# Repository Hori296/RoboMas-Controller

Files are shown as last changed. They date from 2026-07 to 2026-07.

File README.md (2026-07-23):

# RoboMaster Controller

STM32を用いて設計・開発した、RoboMaster M2006 / M3508用モータコントローラです。

本リポジトリでは、回路設計・基板設計・ファームウェアを公開しています。
ロボット開発や組込みシステムで再利用できることを目的として製作しました。

---

## 概要

本コントローラは、DJI RoboMasterシリーズのM2006・M3508モータをCAN通信で制御するためのモータコントローラです。

速度制御・位置制御の両方に対応しており、連続角度推定やソフトウェアによる原点リセットなど、ロボット開発で扱いやすい機能を実装しています。

---

## 主な機能

- M2006 / M3508 モータ対応
- CAN通信による制御
- 速度制御（PID）
- 位置制御（カスケードPID）
- エンコーダ多回転角度推定
- ソフトウェア原点リセット
- 通信タイムアウト保護（500 ms）
- デバッグ情報送信（速度・位置誤差）
- RGB LEDによる状態表示

---

## 設計方針・意図

本コントローラは、M2006・M3508を今後のロボット開発で繰り返し利用できることを目的として設計しています。  
機能追加を前提とするのではなく、速度制御・位置制御・多回転角度推定・通信タイムアウト保護など、実際のロボット運用に必要な機能を一つの基板にまとめています。  
私自身がM2006・M3508モータを複数所有しており、今後のロボット開発でも継続して使用する予定です。そのため、毎回制御プログラムを作り直すことなく、共通で利用できるモータコントローラとして設計しました。

---

## ハードウェア

### マイコン

- STM32F446RE

### 通信

- CAN1
    - 上位PC・マイコンとの通信
- CAN2
    - RoboMaster ESCとの通信

### 制御周期

- 制御周期：1 ms（タイマ割り込み）
- CAN受信：受信割り込み

---

## 通信仕様

### 制御コマンド
|ID|num|
|---|---|
|0x221|motor1|
|0x222|motor2|
|0x223|motor3|
|0x224|motor4|

|Byte|内容|
|---|---|
|0|モータ種類|
|1|制御モード|
|2-3|目標値(int16 /1000)|
|4|Enable|
|5|角度リセット|
|6-7|予約|

### モータ種類

|値|内容|
|---|---|
|1|M2006|
|2|M3508|

### 制御モード

|値|内容|
|---|---|
|1|速度制御|
|2|位置制御|

### デバッグ情報

|ID|0~1|2~3|4~5|6~7|
|---|---|---|---|---|
|0x220|motor1_diff|motor2_diff|motor3_diff|motor4_diff|

---

## 安全機能

500 ms以上制御コマンドを受信しなかった場合、

- モータ停止
- PIDリセット
- 出力0

を実行し、通信断による暴走を防止します。

---

## 写真

|基板|3D|
|---|---|
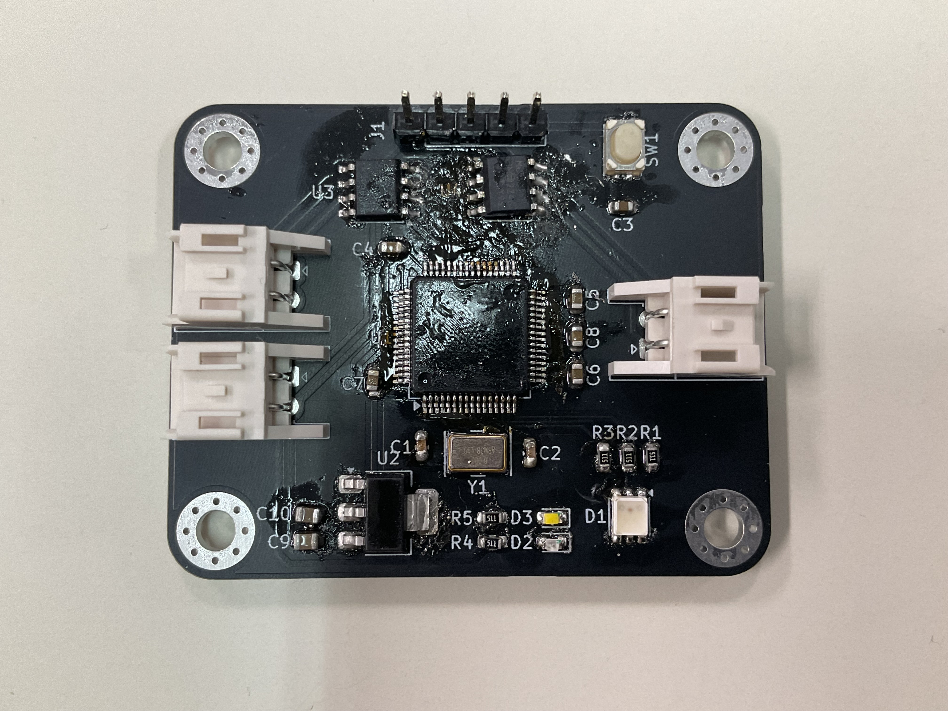
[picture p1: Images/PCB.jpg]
PCB
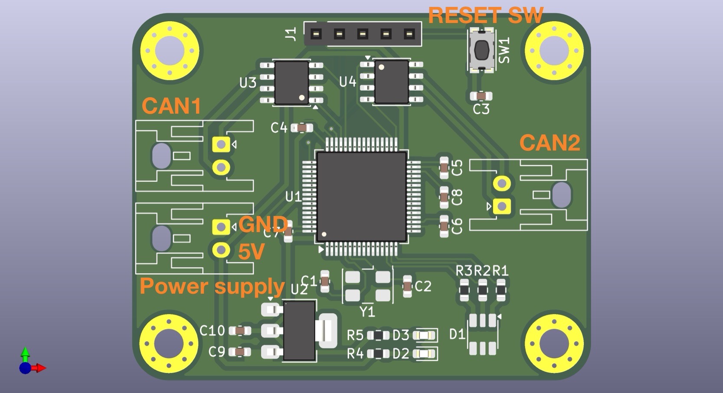
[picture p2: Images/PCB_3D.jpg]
3D
|||

---

## 動作

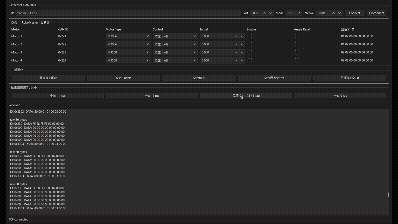
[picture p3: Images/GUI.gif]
demo_GUI

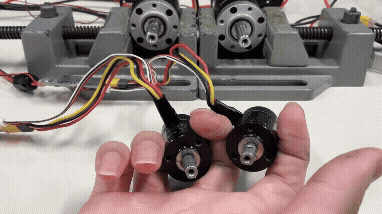
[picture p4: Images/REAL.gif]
demo_3D

demo_LED

※gif画像のためにいろいろしたら，LEDの色おかしくなった( ˊᵕˋ ;)

---

## フォルダ構成

```
Firmware/
    inc
    src
    README

PCB/
    pcb
    sch
    step
    production (JLCPCB発注用)
    README
```

---

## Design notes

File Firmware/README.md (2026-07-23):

# Firmware

## 環境
- system work bench for STM32
- HAL Driver : v1.7.5 (CAN Legacy)
- STMStudio
- 舞鶴高専ロボコン部内ライブラリ使用（Sken_library）

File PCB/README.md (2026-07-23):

# 回路設計

## 環境
- KiCad 9.0

## 使用部品
- STM32F446RET6
- MCP2551-I-SN $\times 2$
- AZ118Ch-3.3TRG1
- SMLVN6RGB
- XA-Connector 2pin $\times 3$

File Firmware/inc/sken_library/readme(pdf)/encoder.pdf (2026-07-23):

# encoder

## インクリメンタル式ロータリーエンコーダのパルスをカウントするクラス．

# struct Encoder_data

## エンコーダからの取得値を格納する関数。タイマー割り込みと合わせるて使う。

[要素]

## カウンタ値 回転数[回転]

角度[°]

## 移動距離[mm]

## 速度[mm/s] 回転速度[rps]

## [要素一覧]

# class Encoder

# void Encoder::init(Pin a_pin,Pin b_pin,TimerNumber tim_num)

## エンコーダのピンとタイマー番号を設定する． 使用することができるタイマーは1,2,3,4,5,8のチャンネル1とチャンネル2である． エンコーダのカウントに使用するタイマーはチャンネル3とチャンネル4も含めてPWM出力に使用する ことはできない．

## [パラメータ] チャンネル1のピン番号 チャンネル2のピン番号 タイマー番号

## [戻り値]

なし

## [サンプルコード] タイマー2をエンコーダモードに設定する

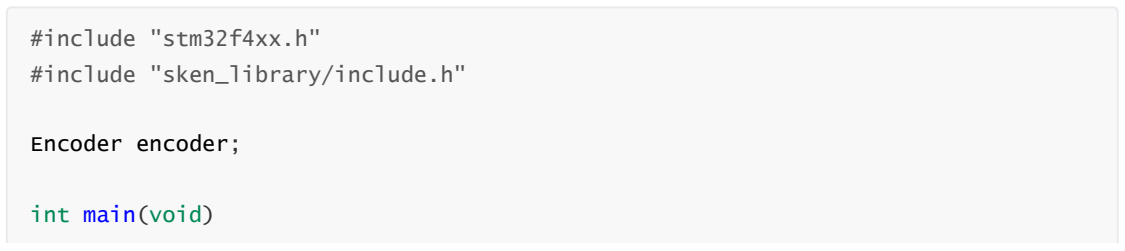
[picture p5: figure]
#include "stm32f4xx.h"; #include "sken_library/include.h"; Encoder encoder;; int main(void)

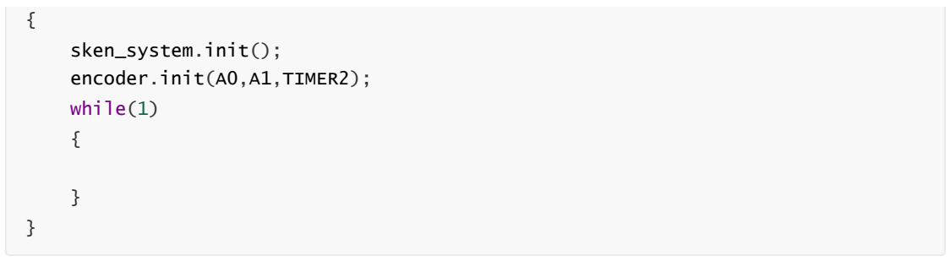
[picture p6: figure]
sken_system.init();; encoder.init(A0,A1,TIMER2);; while(1)

# int Encoder::read(void)

## カウンタの値を取得することができる． カウンタの値は-30000から30000までである．

## [パラメータ]

なし

## [戻り値] カウンタ値

## [サンプルコード]

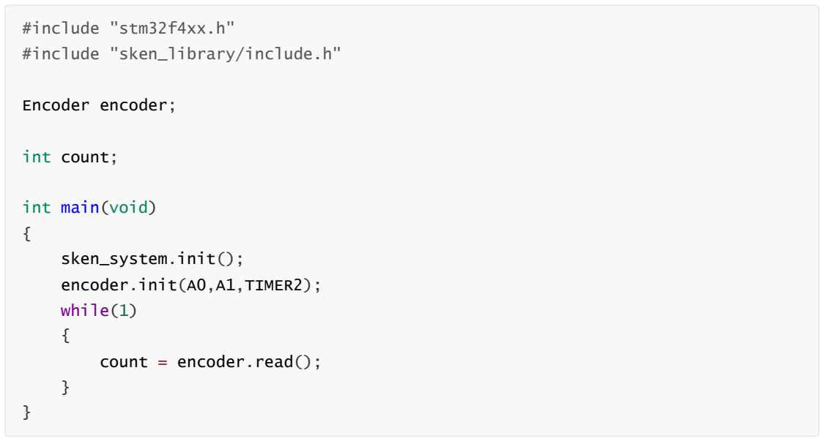
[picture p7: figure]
#include "stm32f4xx.h"; #include "sken_library/include.h"; Encoder encoder;; int count;; int main(void); sken_system.init();; encoder.init(A0,A1,TIMER2);; while(1); count = encoder.read();

# void Encoder::interrupt(Encoder_data* encoder_data)

## Encoder_data構造体にエンコーダからの取得値を格納する関数。タイマー割り込み関数内で使用す

る。

## [パラメータ]

## Encoder_data構造体アドレス

## [戻り値]

なし

## [サンプルコード] タイマー割り込みで取得値を格納する

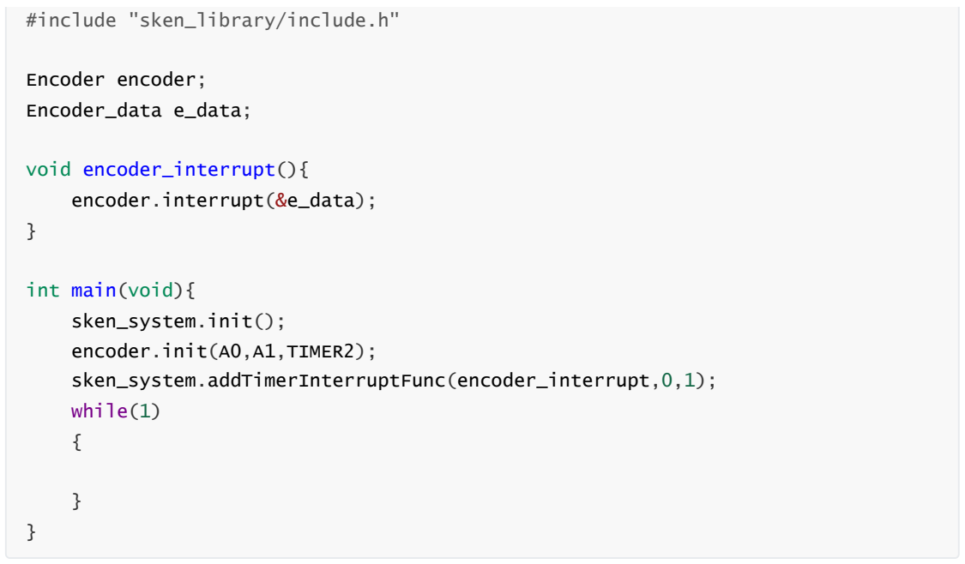
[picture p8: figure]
#include "sken_library/include.h"; Encoder encoder;; Encoder_data e_data;; void encoder_interrupt(){; encoder.interrupt(&e_data);; int main(void){; sken_system.init();; encoder.init(A0,A1,TIMER2);; sken_system.addTimerInterruptFunc(encoder_interrupt,0,1);; while(1)

# void Encoder::reset(void)

## カウンタの値をリセットする

## [パラメータ]

なし

## [戻り値]

なし

## [サンプルコード] カウンタの値が10000を超えた時にリセットする

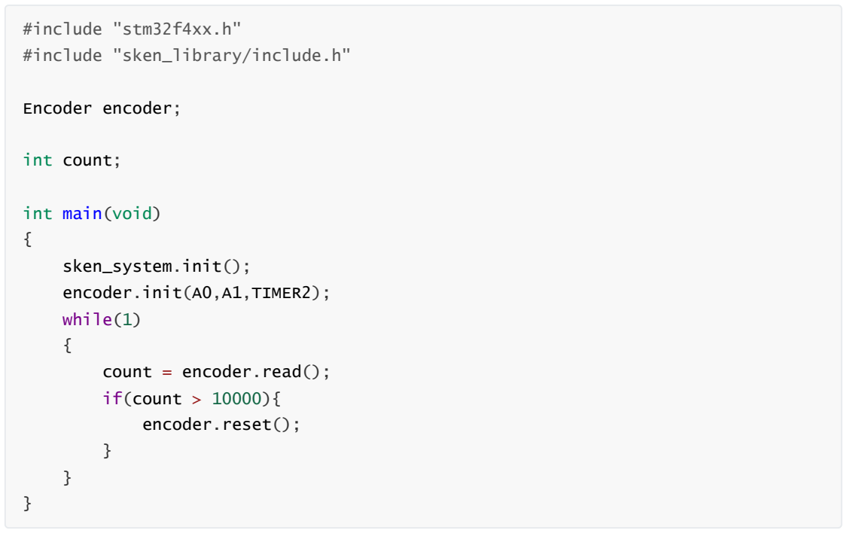
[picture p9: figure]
#include "stm32f4xx.h"; #include "sken_library/include.h"; Encoder encoder;; int count;; int main(void); sken_system.init();; encoder.init(A0,A1,TIMER2);; while(1); count = encoder.read();; if(count > 10000){; encoder.reset();

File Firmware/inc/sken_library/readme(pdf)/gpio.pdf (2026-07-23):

# gpio

## GPIOピンの⼊出⼒をあつかう

# enum Mode

## ⼊出⼒の設定

# enum PinState

## ⼊出⼒状態

# class Gpio

# void Gpio::init(Pin pin,Mode pin_mode)

## ピンの⼊出⼒設定 デジタル出⼒とデジタル⼊⼒の設定で使⽤する． [パラメータ] ピン番号 ⼊出⼒の設定

## [戻り値]

なし

## [サンプルコード] A5ピンをデジタル出⼒に設定する

LOW
HIGH

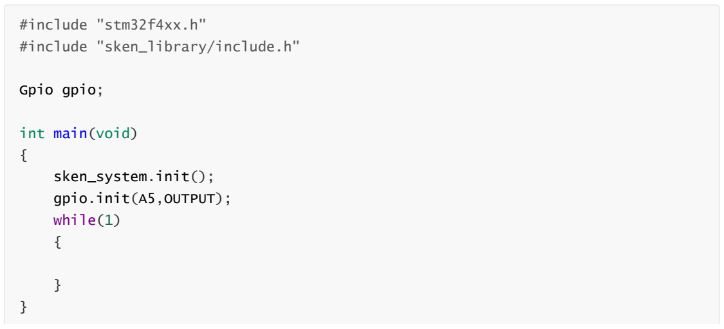
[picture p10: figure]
#include "stm32f4xx.h"; #include "sken_library/include.h"; Gpio gpio;; int main(void); sken_system.init();; gpio.init(A5,OUTPUT);; while(1)

# void Gpio::init(Pin pin,Mode pin_mode,TimerNumber tim_num,TimerChannel tim_ch,int frequency = 16800)

## ピンの⼊出⼒設定 PWM出⼒の設定で使⽤する．

## [パラメータ] ピン番号 ⼊出⼒の設定 タイマー番号 タイマーチャンネル

## PWM周波数

## [戻り値]

なし

## [サンプルコード] A5ピンをPWM出⼒に設定する

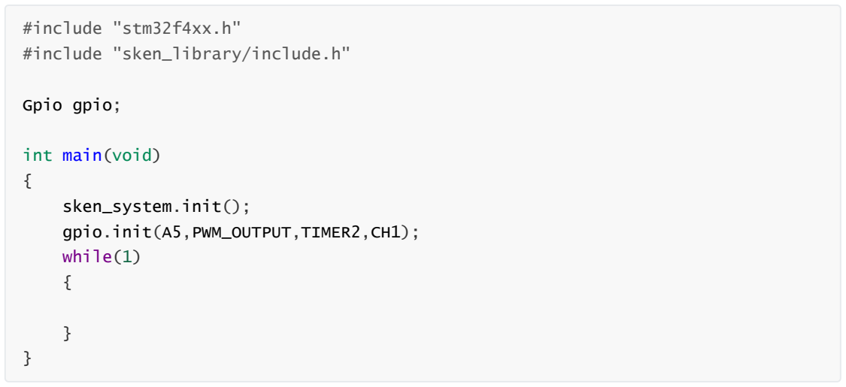
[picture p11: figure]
#include "stm32f4xx.h"; #include "sken_library/include.h"; Gpio gpio;; int main(void); sken_system.init();; gpio.init(A5,PWM_OUTPUT,TIMER2,CH1);; while(1)

# void Gpio::write(PinState state)

## 出⼒に設定している場合，ピンからHIGHまたはLOWを出⼒することができる

## [パラメータ] 出⼒状態 [戻り値]

なし

## [サンプルコード] A5ピンをデジタル出⼒に設定し，HIGHを出⼒する

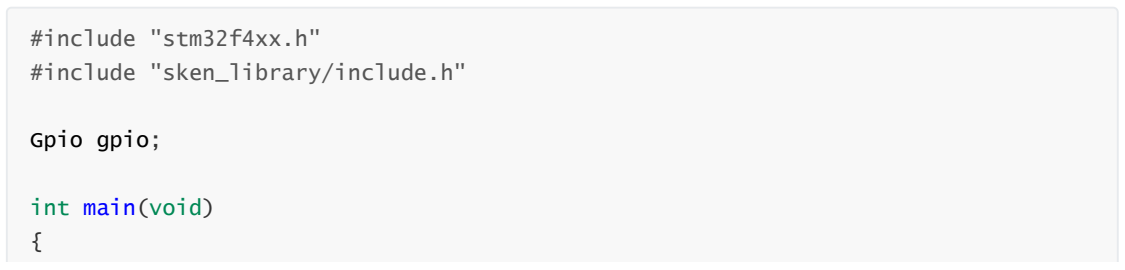
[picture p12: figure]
#include "stm32f4xx.h"; #include "sken_library/include.h"; Gpio gpio;; int main(void)

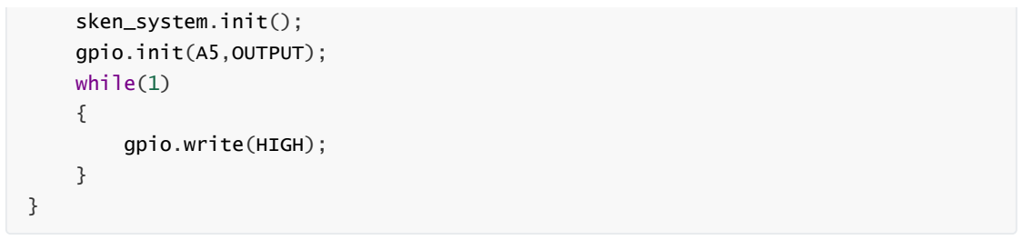
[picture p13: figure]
sken_system.init();; gpio.init(A5,OUTPUT);; while(1); gpio.write(HIGH);

# void Gpio::write(double percentage)

## PWM出⼒に設定されている場合矩形波が出⼒される． ただし，同じタイマーにエンコーダやRCサーボ信号を使⽤している場合はたとえチャンネルが違った としても正しい出⼒が⾏われない． [パラメータ]

出⼒[%]

## [戻り値]

なし

## [サンプルコード] A5ピンから50%のPWMを出⼒する

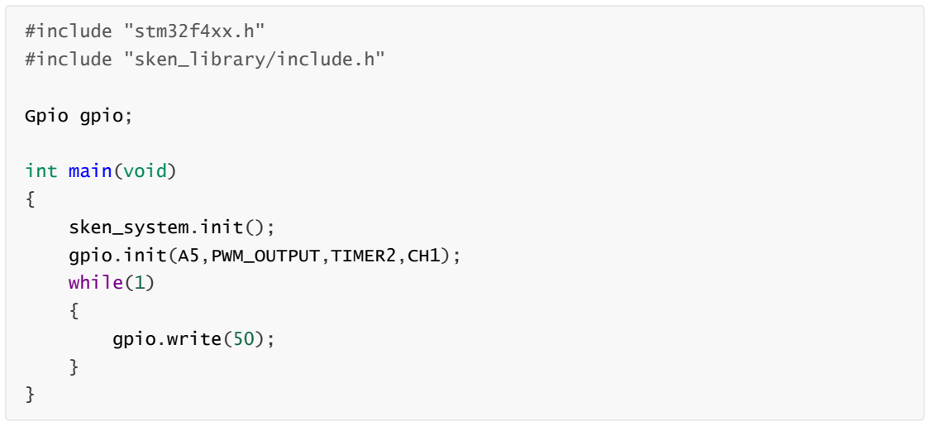
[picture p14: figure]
#include "stm32f4xx.h"; #include "sken_library/include.h"; Gpio gpio;; int main(void); sken_system.init();; gpio.init(A5,PWM_OUTPUT,TIMER2,CH1);; while(1); gpio.write(50);

# bool Gpio::read(void)

## ⼊⼒に設定している場合，ピンの値を読み取ることができる

## [パラメータ]

なし

## [戻り値]

## HIGHのときtrue，LOWのときfalse

## [サンプルコード] C13ピンに接続したスイッチを読む

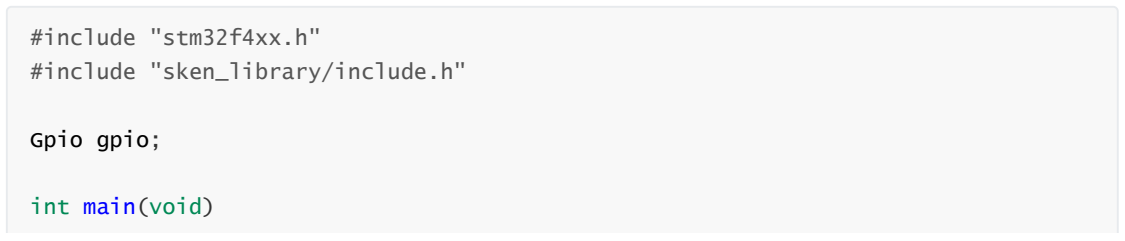
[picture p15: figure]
#include "stm32f4xx.h"; #include "sken_library/include.h"; Gpio gpio;; int main(void)

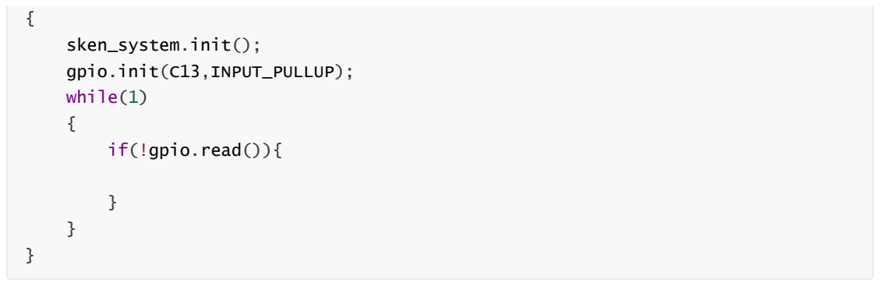
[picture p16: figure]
sken_system.init();; gpio.init(C13,INPUT_PULLUP);; while(1); if(!gpio.read()){

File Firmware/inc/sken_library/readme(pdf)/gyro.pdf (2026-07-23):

# gyro

## R6093ジャイロを扱うクラス

# enum Cordinate{

}

# struct gyro_data_t{

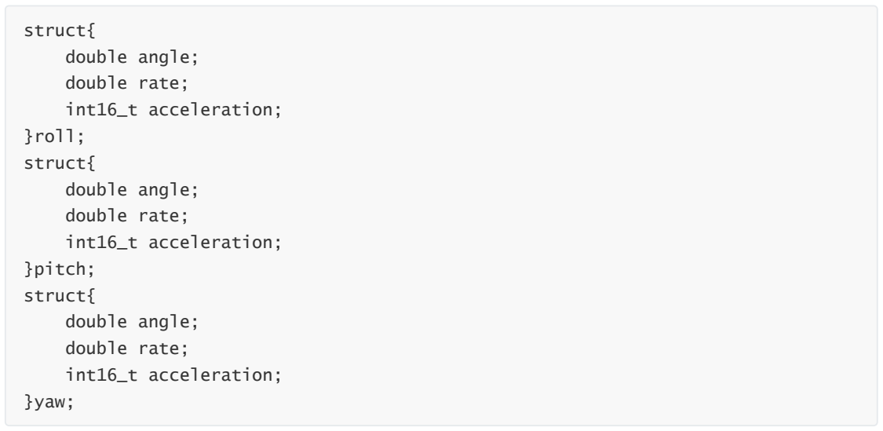
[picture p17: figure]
struct{; double angle;; double rate;; int16_t acceleration;; }roll;; }pitch;; }yaw;

}

# class Gyro

# void Gyro::init(Pin tx_pin,Pin rx_pin,UartNumber uart_num,int connect_dead_time = 1000)

## シリアルピンの設定を⾏う [パラメータ] 送信ピン番号 受信ピン番号 シリアル番号 通信切断時間

## [戻り値]

なし

## [サンプルコード]

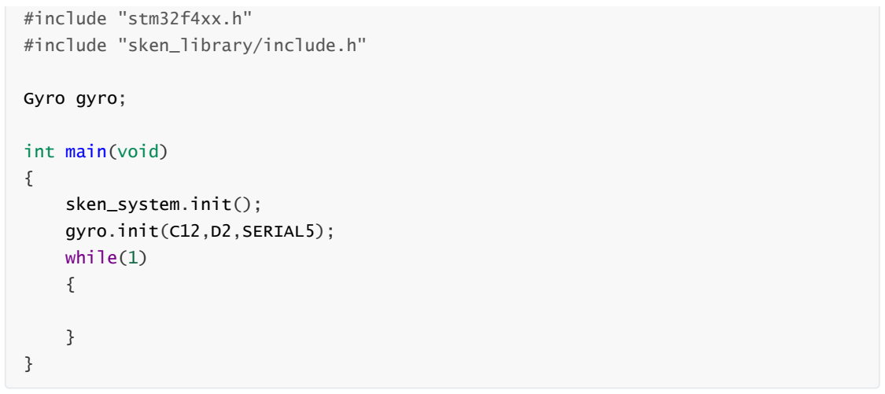
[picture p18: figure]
#include "stm32f4xx.h"; #include "sken_library/include.h"; Gyro gyro;; int main(void); sken_system.init();; gyro.init(C12,D2,SERIAL5);; while(1)

# bool Gyro::update(void)

## ジャイロからのデータを更新する [パラメータ]

なし

## [戻り値] 成功したらtrue，失敗したらfalse [サンプルコード]

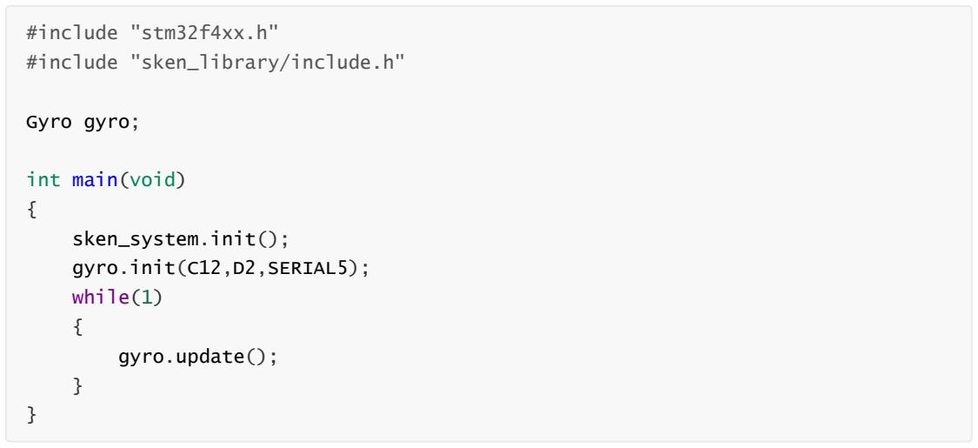
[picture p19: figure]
#include "stm32f4xx.h"; #include "sken_library/include.h"; Gyro gyro;; int main(void); sken_system.init();; gyro.init(C12,D2,SERIAL5);; while(1); gyro.update();

# bool Gyro::resetAngle(Cordinate coordinate)

## ジャイロの⾓度を0度にリセットする

## [パラメータ] リセットする軸 [戻り値] 成功したらtrue，失敗したらfalse [サンプルコード] 1秒ごとにロール軸をリセットする

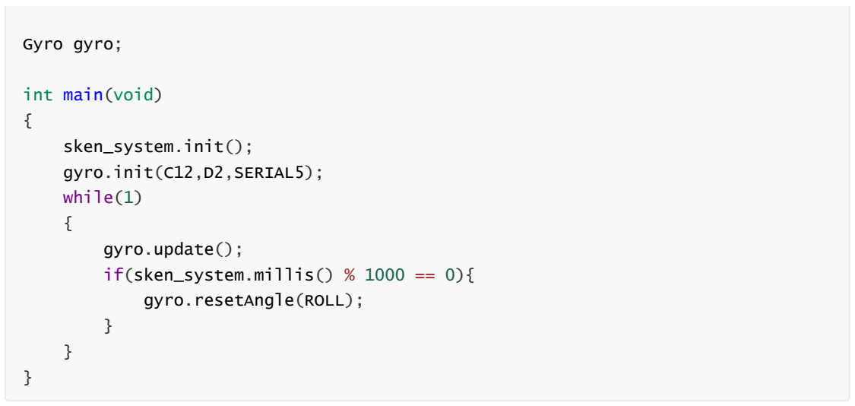
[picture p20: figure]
Gyro gyro;; int main(void); sken_system.init();; gyro.init(C12,D2,SERIAL5);; while(1); gyro.update(); if(sken_system.millis() % 1000 == 0){; gyro.resetAngle(ROLL);

# bool Gyro::getConnectFlag(void)

## 接続確認フラグを取得する [パラメータ]

なし

## [戻り値] 接続していたらtrue，接続していなかったらfalse [サンプルコード]

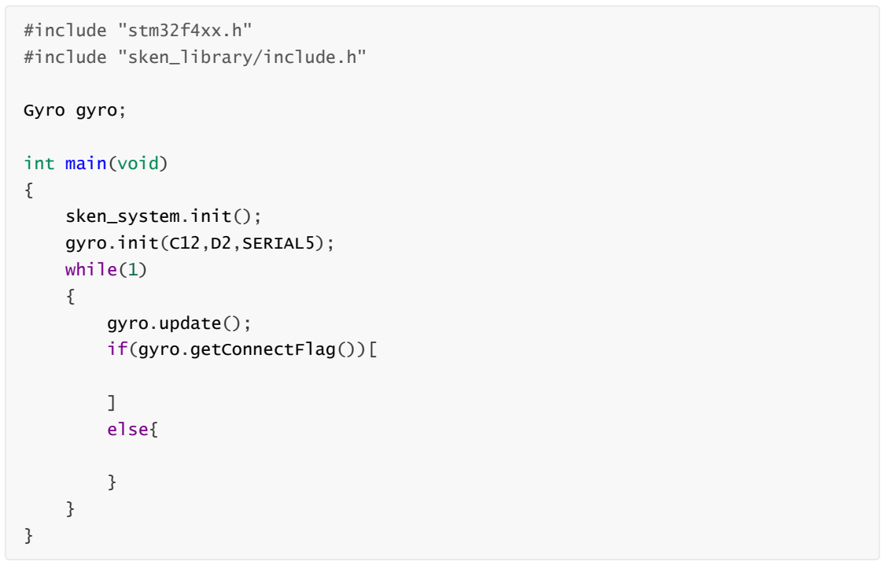
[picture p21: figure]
#include "stm32f4xx.h"; #include "sken_library/include.h"; Gyro gyro;; int main(void); sken_system.init();; gyro.init(C12,D2,SERIAL5);; while(1); gyro.update(); if(gyro.getConnectFlag())[; else{

# gyro_data_t Gyro::getData(void)

## ⾓度等のデータを取得する

## [パラメータ]

なし

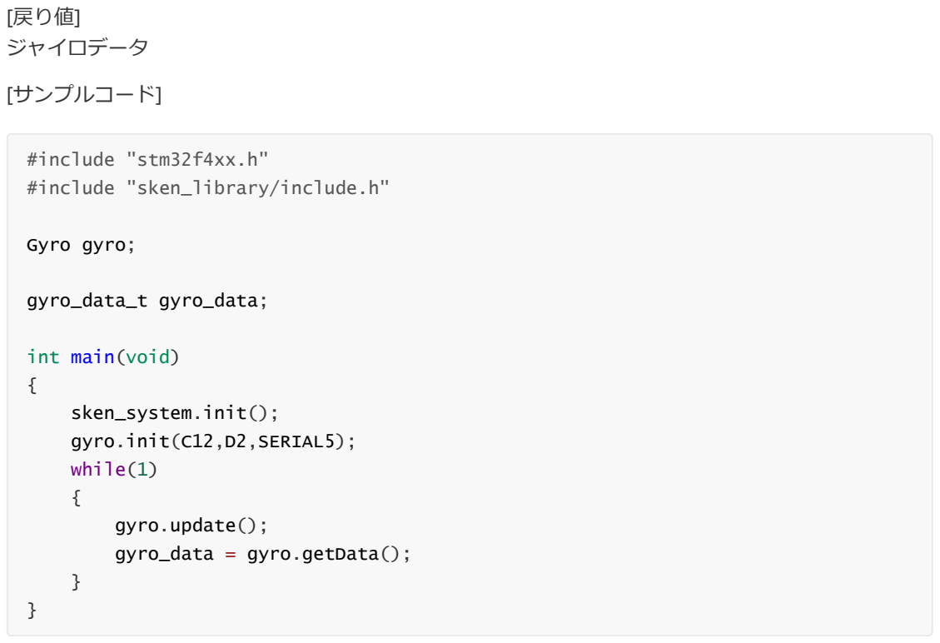
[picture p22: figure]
[戻り値] ジャイロデータ; [サンプルコード]; #include "stm32f4xx.h"; #include "sken_library/include.h"; Gyro gyro;; gyro_data_t gyro_data;; int main(void); sken_system.init();; gyro.init(C12,D2,SERIAL5);; while(1); gyro.update();; gyro_data = gyro.getData();

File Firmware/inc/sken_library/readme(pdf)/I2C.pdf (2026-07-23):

I2C

## I2C通信を行う

# class I2C

# void I2C::init(Pin scl,Pin sda,I2CSelect i2c,int clockspeed)

## I2C通信の初期化

## [パラーメタ]

## sclピン sdaピン I2C番号

## クロックスピード[Hz]

## [サンプルコード] I2C通信初期

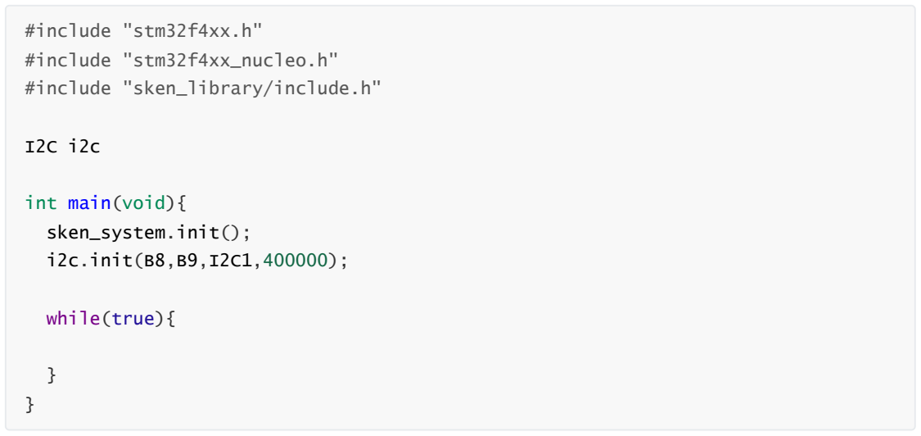
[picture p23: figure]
#include "stm32f4xx.h"; #include "stm32f4xx_nucleo.h"; #include "sken_library/include.h"; int main(void){; sken_system.init();; i2c.init(B8,B9,I2C1,400000);; while(true){

# void I2C::write(uint16_t DevAddress, uint16_t

MemAddress, uint16_t MemAddSize, uint8_t *pData,

# uint16_t Size, uint32_t Timeout = 100)

## 送信関数

## [パラメータ] デバイスアドレス メモリーアドレス メモリーアドレスサイズ 送信データアドレス 送信データサイズ タイムアウト時間[ms]

## [サンプルコード] 8バイトのデータを送信

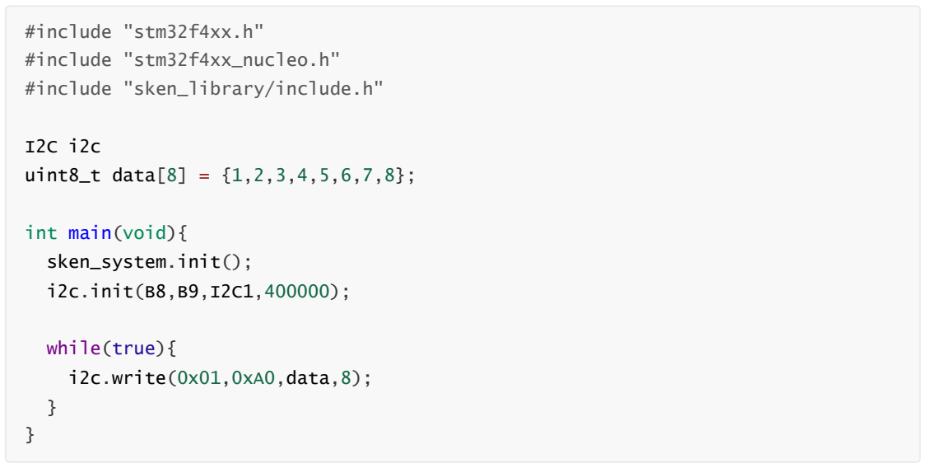
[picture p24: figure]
#include "stm32f4xx.h"; #include "stm32f4xx_nucleo.h"; #include "sken_library/include.h"; uint8_t data[8] = {1,2,3,4,5,6,7,8};; int main(void){; sken_system.init();; i2c.init(B8,B9,I2C1,400000);; while(true){; i2c.write(0x01,0xA0,data,8);

# void I2C::read(uint16_t DevAddress, uint16_t

MemAddress, uint16_t MemAddSize, uint8_t *pData,

# uint16_t Size, uint32_t Timeout = 100)

## 受信関数

## [パラメータ] デバイスアドレス メモリーアドレス メモリーアドレスサイズ 受信データアドレス 受信データサイズ タイムアウト時間[ms]

## [サンプルコード] 8バイトのデータを受信

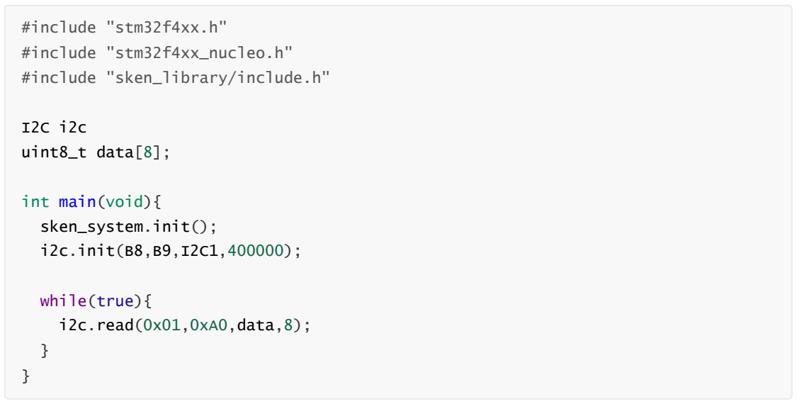
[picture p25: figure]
#include "stm32f4xx.h"; #include "stm32f4xx_nucleo.h"; #include "sken_library/include.h"; uint8_t data[8];; int main(void){; sken_system.init();; i2c.init(B8,B9,I2C1,400000);; while(true){; i2c.read(0x01,0xA0,data,8);

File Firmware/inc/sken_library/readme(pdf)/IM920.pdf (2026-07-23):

IM920

通信モジュール、IM920sLを使用するためのクラス.

# enum IM920Bytes

## Bytes8：8バイトの送受信のために使う Bytes16：16バイトの送受信のために使う Bytes24：24バイトの送受信のために使う Bytes32：32バイトの送受信のために使う

# class IM920

# IM920::init(Pin tx_pin,Pin rx_pin,UartNumber uart_num)

## 初期化関数

## [パラメータ] 送信ピン番号 受信ピン番号 シリアル番号

## [戻り値]

なし

## [サンプルコード]

オブジェクトを作成し、初期化する.

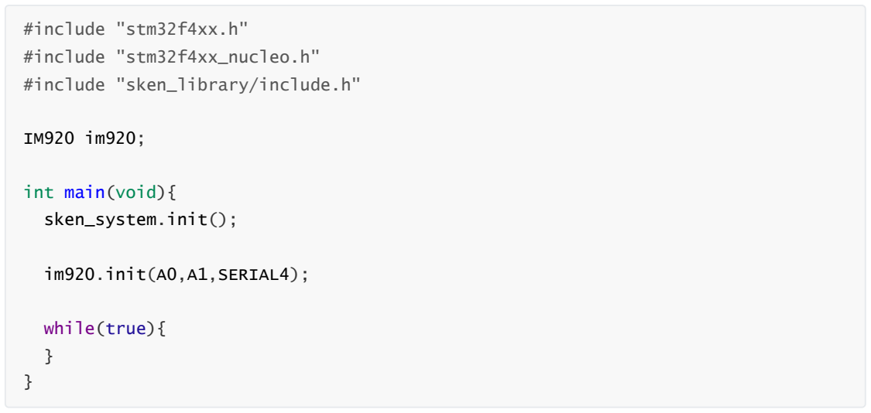
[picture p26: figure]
#include "stm32f4xx.h"; #include "stm32f4xx_nucleo.h"; #include "sken_library/include.h"; int main(void){; sken_system.init();; im920.init(A0,A1,SERIAL4);; while(true){

# IM920::read(uint16_t* rx_id,uint8_t* rx_data,IM920Bytes bytes)

## 受信関数

## [パラメータ] 受信先のノード番号を格納するための変数のアドレス 受信データを格納するための配列のアドレス 受信データの大きさ

## [戻り値]

なし

## [サンプルコード] 受信データを８バイトで取得

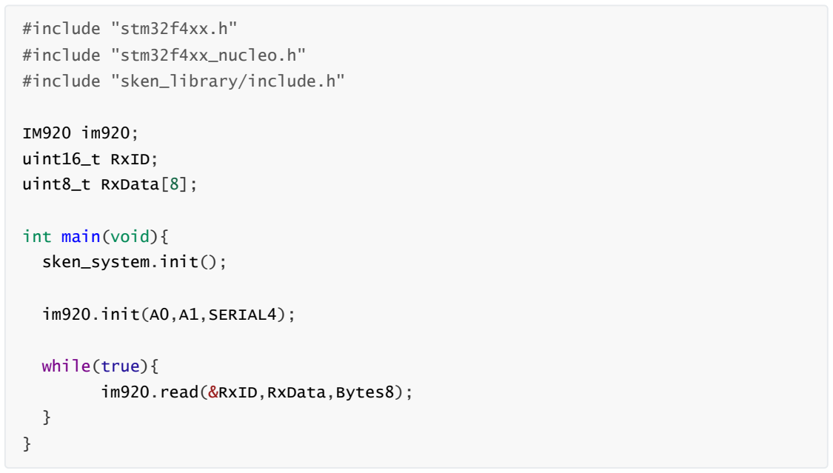
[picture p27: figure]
#include "stm32f4xx.h"; #include "stm32f4xx_nucleo.h"; #include "sken_library/include.h"; uint16_t RxID;; uint8_t RxData[8];; int main(void){; sken_system.init();; im920.init(A0,A1,SERIAL4);; while(true){; im920.read(&RxID,RxData,Bytes8);

# IM920::write(uint8_t* tx_data,IM920Bytes bytes,int node_num = 0x0000)

## 送信関数

## [パラメータ] 送信データ配列のアドレス 送信データの大きさ 送信先のノード番号（省略すると全てのノードに送信される）

## [戻り値]

なし

## [サンプルコード] 8バイトのデータを送信

#include "stm32f4xx.h"

#include "stm32f4xx_nucleo.h" #include "sken_library/include.h"

IM920 im920;
uint8_t TxData[8] = {0x91,0xA2,0xB3,0xC4,0xD5,0xE6,0xF7,0x08};

int main(void){
sken_system.init();

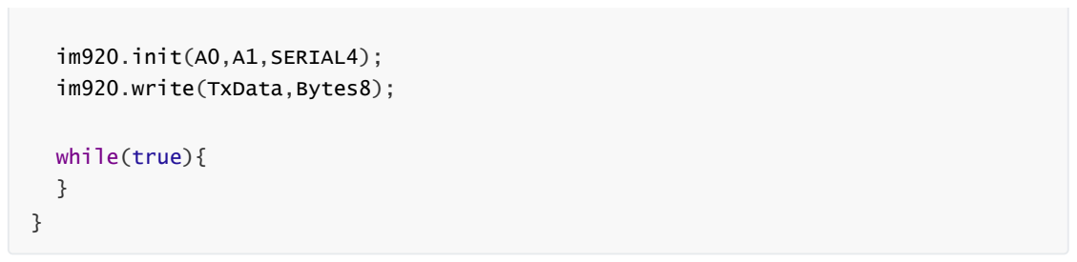
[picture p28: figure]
im920.init(A0,A1,SERIAL4);; im920.write(TxData,Bytes8);; while(true){

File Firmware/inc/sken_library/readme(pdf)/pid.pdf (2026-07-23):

# pid

## PID制御を⾏うクラス

# class Pid

# void Pid::setGain(double p_gain,double i_gain,double d_gain,double time_constant = 0)

## PIDゲインの設定を⾏う [パラメータ] ⽐例制御ゲイン 積分制御ゲイン 微分制御ゲイン 微分前ローパスフィルタの時定数[ms]

## [戻り値]

なし

## [サンプルコード]

#include "stm32f4xx.h"; #include "sken_library/include.h"; Pid pid_control;; int main(void); sken_system.init();; pid_control.setGain(1,1,1,20);; while(1)

# double Pid::control(double target,double now,int control_period)

## ⽬標値と現在値からPID制御を⾏う

## [パラメータ]

⽬標値

## 現在値 制御周期[ms] [戻り値] 制御出⼒ [サンプルコード]

#include "stm32f4xx.h"; #include "sken_library/include.h"; Pid pid_control;; double target;; double now;; double out;; void func(void); out = pid_control.control(target,now,1);; int main(void); sken_system.init();; pid_control.setGain(1,1,1); sken_system.addTimerInterruptFunc(func,0,1);; while(1)

# double Pid::control(double e,int control_period)

## 偏差からPID制御を⾏う [パラメータ]

偏差

## 制御周期[ms]

## [戻り値] 制御出⼒ [サンプルコード]

#include "stm32f4xx.h"; #include "sken_library/include.h"; Pid pid_control;; double e;; double out;; void func(void); out = pid_control.control(e,1);; int main(void); sken_system.init();; pid_control.setGain(1,1,1); sken_system.addTimerInterruptFunc(func,0,1);; while(1)

# void Pid::reset(void)

## 積分と微分をリセットする

[パラメータ] なし; [戻り値] なし; [サンプルコード] 1秒ごとにPID制御をリセットする; #include "stm32f4xx.h"; #include "sken_library/include.h"; Pid pid_control;; double target;; double now;; double out;; int main(void); sken_system.init();; pid_control.setGain(1,1,1); sken_system.addTimerInterruptFunc(func,0,1);; while(1); if(sken_system.millis() % 1000 == 0){; pid_control.reset();

void func(void)
out = pid_control.control(target,now,1);

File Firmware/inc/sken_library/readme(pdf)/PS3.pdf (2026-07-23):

PS3

## PS3コントローラーを使うためのクラス

# struct PS3_data

## PS3コントローラの受信状態を格納するための構造体 ボタンは押されているときに1、押されていないときに0を返す スティックは、右をX軸の正、上をY軸の正として64～⁻64の値を返す

## [要素内容] ↑ボタン ↓ボタン →ボタン ←ボタン △ボタン ×ボタン ○ボタン □ボタン L1ボタン L2ボタン R1ボタン R2ボタン

## Startボタン Selectボタン

## ジョイスティック（左x軸） ジョイスティック（左y軸） ジョイスティック（右x軸） ジョイスティック（右y軸） 受信データ

## [要素一覧]

struct PS3_data{; Up,Down,Right,Left,Triangle,Cross,Circle,Square,L1,L2,R1,R2,Start,Select;; int LxPad,LyPad,RxPad,RyPad;; uint8_t rx_data[8];

# class PS3

# void PS3::StartRecive(Pin tx_pin = A9,Pin rx_pin =

A10,UartNumber uart_num = SERIAL1);

## PS3コントローラからの受信を開始する

## [パラメータ] 送信ピン番号 受信ピン番号 シリアル番号 （デフォルトで、部室にあるシールド基盤のピン番号、シリアル番号を設定している）

## [戻り値]

なし

## [サンプルコード] ps3コントローラからの受信を開始

#include "stm32f4xx.h"; #include "stm32f4xx_nucleo.h"; #include "sken_library/include.h"; int main(void){; sken_system.init();; ps3.StartRecive();; while(true){

bool Getdata(PS3_data* ps3_data);

## PS3コントローラのデータを取得する

## [パラメータ]

## PS3_deta構造体のアドレス

## [戻り値] 受信データを取得できればtrue、できなければfalse

## [サンプルコード] ps3_dataにPS3コントローラのデータを代入

#include "stm32f4xx.h"; #include "stm32f4xx_nucleo.h"; #include "sken_library/include.h"; PS3_data ps3_data;; int main(void){; sken_system.init();; ps3.StartRecive();; while(true){; ps3.Getdata(&ps3_data);

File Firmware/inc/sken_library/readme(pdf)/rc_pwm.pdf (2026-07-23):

# rc_pwm

## 周期20[ms]のラジコンサーボ信号を制御するクラス．

# class RcPwm

# void RcPwm::init(Pin pin,TimerNumber tim_num,TimerChannel tim_ch)

## ピンとタイマーの設定を⾏う [パラメータ] ピン番号 タイマー番号 タイマーチャンネル

## [戻り値]

なし

## [サンプルコード]

#include "stm32f4xx.h"; #include "sken_library/include.h"; RcPwm rc_pwm;; int main(void); sken_system.init();; rc_pwm.init(A5,TIMER2,CH1);; while(1)

# void RcPwm::turn(double percentage)

## 出⼒の割合を設定する関数

## [パラメータ]

## 出⼒割合(1000[us]から2000[us]の間を0[%]から100[%]で設定)

## [戻り値]

なし

## [サンプルコード]

## 20[%] (1200[us])で出⼒する

int main(void); sken_system.init();; rc_pwm.init(A5,TIMER2,CH1);; while(1); rc_pwm.turn(20);

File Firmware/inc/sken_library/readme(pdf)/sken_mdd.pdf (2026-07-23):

# SkenMdd

## モータドライバドライバ（MDD）を使用するためのクラス

enum MddCommandId; MOTOR_RPS_COMMAND_MODE：目標回転数設定 MOTOR_PWM_COMMAND_MODE：PWM設定 MECANUM_MODE：メカナム動作モード OMNI3_MODE：3輪オムニ動作モード OMNI4_MODE：4輪オムニ動作モード M1_PID_GAIN_CONFIG：モータ1PIDゲイン設定 M2_PID_GAIN_CONFIG：モータ2PIDゲイン設定 M3_PID_GAIN_CONFIG：モータ3PIDゲイン設定 M4_PID_GAIN_CONFIG：モータ4PIDゲイン設定 ROBOT_DIAMETER_CONFIG：車輪直径と旋回直径設定 PID_RESET_COMMAND：PID制御リセット指令 MOTOR_COMMAND_MODE_SELECT：PWM指令モードか回転数指令モードかの選択 ENCODER_RESOLUTION_CONFIG：エンコーダ分解能設定 enum MddStdid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

## [サンプルコード] オブジェクトを生成し，初期化する

#include "stm32f4xx.h"; #include "sken_library/include.h"; #include "sken_mdd.h"; SkenMdd mdd;; int main(void); sken_system.init();; mdd.init(B10,C5,SERIAL3);; while (1) {

# void init(MddStdid stdid,Pin can_tx,Pin can_rx,CanSelect can_select)

## CAN通信を行う際の初期化関数

## [パラメータ] MDDスタンダードID 送信ピン番号 受信ピン番号

## CAN番号

## [戻り値]

なし

## [サンプルコード] オブジェクトを作成し、初期化する

'''c++

## include "stm32f4xx.h" #include "sken_library/include.h" #include "sken_mdd.h"

SkenMdd mdd;

## int main(void)

{
sken_system.init();
mdd.init(MDD_0,A12,A11,CAN_1);

## while (1) {

}

}

# void SkenMdd::udp(uint8_t id,const float (&command_data)[4])

## UDPモードで送信する 回転数指令など何度も送るため1度届かなくても大きな影響のないデータに対して使用する

## [パラメータ] 指令ID 指令データ配列

## [戻り値]

なし

## [サンプルコード] 4つのモータの目標回転数を設定する．

## bool SkenMdd::tcp(uint8_t id,const float (&command_data)[4],unsigned int resend_time,unsigned int max_wait_time)

TCPモードで送信する
パラメータ設定など確実に通信する必要があるデータに対して使用する

[パラメータ]
指令ID
指令データ配列
再送信時間 [ms]
最大待機時間 [ms]

[戻り値]
成功か失敗

[サンプルコード]
モータ1のPIDのゲインを再送時間10 [ms]，最大待機時間2000 [ms]で設定する

``` c++
#include "stm32f4xx.h"

#include "sken_library/include.h"

#include "sken_mdd.h"

const float MOTOR_PID_GAIN[4] = {1.5,0.1,0.1,20};

SkenMdd mdd;

int main(void)
{
sken_system.init();
mdd.init(B10,C5,SERIAL3);
mdd.tcp(M1_PID_GAIN_CONFIG,MOTOR_PID_GAIN,10,2000); while (1) {

}
}

#include "sken_mdd.h"; const float MOTOR_PID_GAIN[4] = {1.5,0.1,0.1,20};; float motor_target_rps[4] = {1,-0.5,1.5,-10};; SkenMdd mdd;; int main(void); sken_system.init();; mdd.init(B10,C5,SERIAL3);; mdd.tcp(M1_PID_GAIN_CONFIG,MOTOR_PID_GAIN,10,2000);; while (1) {; mdd.udp(MOTOR_RPS_COMMAND_MODE,motor_target_rps);

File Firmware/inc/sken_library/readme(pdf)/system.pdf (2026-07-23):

# system

## millisなどの基本的な関数やCAN通信の制御など

# class SYSTEM

# void SYSTEM::init(bool use_external_crystal = false)

## 初期化関数でプログラムで最初に呼び出す必要がある． sken_systemという名前ですでにオブジェクトが⽤意されている [パラメータ] 外部クロック使⽤

## [戻り値]

なし

## [サンプルコード]

#include "stm32f4xx.h"; #include "sken_library/include.h"; int main(void); sken_system.init();; while(1)

# unsigned int SYSTEM::micros(void)

## マイコン起動時からの時間をマイクロ秒で返す．

## [パラメータ]

なし

## [戻り値] マイコン起動時からの時間 [サンプルコード] マイコン起動時からの時間を取得する．

#include "stm32f4xx.h"; #include "sken_library/include.h"; unsigned int time;; int main(void); sken_system.init();; while(1); time = sken_system.micros();

# unsigned int SYSTEM::millis(void)

## マイコン起動時からの時間をミリ秒で返す． [パラメータ]

なし

## [戻り値] マイコン起動時からの時間 [サンプルコード] マイコン起動時からの時間を取得する．

#include "stm32f4xx.h"; #include "sken_library/include.h"; unsigned int time;; int main(void); sken_system.init();; while(1); time = sken_system.millis();

# void SYSTEM::delayMillis(unsigned int delay_time_millis)

## プログラムを指定した時間だけ停⽌させる． 単位はミリ秒．

## [パラメータ] 停⽌時間 [戻り値]

なし

## [サンプルコード] 1秒待ってからループに⼊る．

#include "stm32f4xx.h"; #include "sken_library/include.h"; int main(void); sken_system.init();; sken_system.delayMillis(1000);; while(1)

# void SYSTEM::delayMicros(unsigned int delay_time_micros)

## プログラムを指定した時間だけ停⽌させる． 単位はマイクロ秒． [パラメータ] 停⽌時間

## [戻り値]

なし

## [サンプルコード] 1ミリ秒待ってからループに⼊る．

#include "stm32f4xx.h"; #include "sken_library/include.h"; int main(void); sken_system.init();; sken_system.delayMicros(1000);; while(1)

# bool SYSTEM::addTimerInterruptFunc(void(*function_p) (void),int id,int period = 1)

## タイマー割り込み関数を追加する．

## [パラメータ] タイマー割り込み時に呼び出す関数のアドレス． 関数に与えるID．0から7の間で選択する． 関数の呼び出し周期．デフォルトは1[ms]である． [戻り値] 成功したらtrue，失敗したらfalse．

## [サンプルコード] 1[ms]ごとにカウンタをインクリメントする．

#include "stm32f4xx.h"; #include "sken_library/include.h"; unsigned int counter;; void func(void); counter++;; int main(void); sken_system.init(); sken_system.addTimerInterruptFunc(func,0,1);; while(1)

# bool SYSTEM::deleteTimerInterruptFunc(int id)

## 指定したIDのタイマー割り込み関数を削除する． [パラメータ] 削除する関数のID．0から7の間で選択する．

## [戻り値] 成功したらtrue，失敗したらfalse [サンプルコード] 1[ms]ごとにカウンタをインクリメントし，1000を超えたら停⽌する．

#include "stm32f4xx.h"; #include "sken_library/include.h"; unsigned int counter;; void func(void); counter++;; int main(void); sken_system.init(); sken_system.addTimerInterruptFunc(func,0,1);; while(1); if(counter > 1000){; deleteTimerInterruptFunc(0);

# bool SYSTEM::changeTimerInterruptPeriod(int id,int period)

## 指定したIDのタイマー割り込み関数の周期を変更する．

## [パラメータ] 周期を変更する関数のID．0から7の間で選択する． [戻り値] 成功したらtrue，失敗したらfalse [サンプルコード] 1[ms]ごとにカウンタをインクリメントし，1000を超えたら2[ms]ごとにカウンタをインクリメントす

る．

#include "stm32f4xx.h"; #include "sken_library/include.h"; unsigned int counter;; void func(void); counter++;; int main(void); sken_system.init(); sken_system.addTimerInterruptFunc(func,0,1);; while(1); if(counter > 1000){; changeTimerInterruptPeriod(0,2);

# bool SYSTEM::startCanCommunicate(PIN tx_pin,PIN rx_pin,CAN_SELECT can_select)

## CAN通信を開始する． 通信速度は1[Mbps]である．

## [パラメータ]

## CAN_TXピン CAN_RXピン CAN番号．CAN_1かCAN_2から選択．

## [戻り値] 成功したらtrue，失敗したらfalse

## [サンプルコード] CAN_1の通信を開始する．

#include "stm32f4xx.h"; #include "sken_library/include.h"; int main(void); sken_system.init();; sken_system.startCanCommunicate(B9,B8,CAN_1);; while(1)

# bool SYSTEM::canTrancemit(CAN_SELECT can_select,uint32_t stdid,uint8_t* data_p,int data_size,int dead_time = 10)

## CAN通信で送信する． [パラメータ]

## CAN番号．CAN_1かCAN_2から選択．

## CAN通信におけるスタンダードID． 送信データアドレス． 送信データ数． デッドタイム．デフォルトは10[ms]である．

## [戻り値] 成功したらtrue，失敗したらfalse [サンプルコード] CAN_1でデータを送信する．

#include "stm32f4xx.h"; #include "sken_library/include.h"; uint8_t can_transmit_data_1[8] = {};; int main(void); sken_system.init();; sken_system.startCanCommunicate(B9,B8,CAN_1);; while(1); sken_system.canTrancemit(CAN_1,0x1010,can_transmit_data_1,8);

# bool SYSTEM::addCanRceiveInterruptFunc(CAN_SELECT can_select,void(*function_p)(CanRxMsgTypeDef),int

id)

## CAN通信で受信割り込み関数を追加する．

## [パラメータ]

## CAN番号．CAN_1かCAN_2から選択．

## 受信割り込み時に呼び出す関数のアドレス． 関数に与えるID．0から7の間で選択する． [戻り値] 成功したらtrue，失敗したらfalse

## [サンプルコード] CAN_1の受信割り込み関数を追加する．

#include "stm32f4xx.h"; #include "sken_library/include.h"; void func(CanRxMsgTypeDef); int main(void); sken_system.init();; sken_system.startCanCommunicate(B9,B8,CAN_1); sken_system.addCanRceiveInterruptFunc(CAN_1,func,0);; while(1)

# bool SYSTEM::deleteCanRceiveInterruptFunc(CAN_SELECT can_select,int id)

## CAN通信で受信割り込み関数を削除する． [パラメータ]

## CAN番号．CAN_1かCAN_2から選択．

## 削除する関数のID．0から7の間で選択する．

## [戻り値] 成功したらtrue，失敗したらfalse [サンプルコード] CAN_1の受信割り込み関数を1秒後に削除する．

#include "stm32f4xx.h"

#include "sken_library/include.h"

void func(CanRxMsgTypeDef)
{

}

int main(void)
{

sken_system.init();
sken_system.startCanCommunicate(B9,B8,CAN_1); sken_system.addCanRceiveInterruptFunc(CAN_1,func,0); sken_system.delayMillis(1000); sken_system.deleteCanRceiveInterruptFunc(CAN_1,0); while(1)
{

}
}

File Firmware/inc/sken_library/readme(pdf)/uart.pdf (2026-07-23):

# uart

## UART通信を制御するクラス ポーリングモードでの送受信とDMA(Direct Memory Access)を使⽤した受信を⾏うことができる

# class Uart

# void Uart::init(Pin tx_pin,Pin rx_pin,UartNumber uart_num,int baudrate,uint32_t parity = UART_PARITY_NONE)

## シリアル通信の初期化を⾏う関数 [パラメータ] 送信ピン番号 受信ピン番号 シリアル番号 転送レート．単位は[bps] パリティ.デフォルトではなし

## [戻り値]

なし

## [サンプルコード] UART1をボーレート9600で設定する

#include "stm32f4xx.h"; #include "sken_library/include.h"; Uart serial;; int main(void); sken_system.init();; serial.init(A9,A10,SERIAL1,9600);; while(1)

# void Uart::startDmaRead(uint8_t* data_p,int data_size)

## データ受信をDMAで⾏うための設定を⾏う関数．配列の先頭アドレスと要素数を指定することでリン グ状にデータを格納する．

## [パラメータ] 格納先配列の先頭アドレス 格納先配列の⼤きさ

## [戻り値]

なし

## [サンプルコード] 2バイトのデータをDMAで受信する

#include "stm32f4xx.h"; #include "sken_library/include.h"; Uart serial;; uint8_t data[2];; int main(void); sken_system.init();; serial.init(A9,A10,SERIAL1,9600);; serial.startDmaRead(data,2);; while(1)

# uint8_t Uart::read(unsigned int dead_time)

## ポーリングモードでデータを受信する関数．デッドタイム以上の時間，データが受信できなかった場 合タイムアウトフラグがtrueになる．

## [パラメータ] 受信待ち時間 [戻り値] 受信データ

## [サンプルコード]

#include "stm32f4xx.h"; #include "sken_library/include.h"; Uart serial;; uint8_t data;; int main(void); sken_system.init();; serial.init(A9,A10,SERIAL1,9600);; while(1); data = serial.read(1000);

# void Uart::write(uint8_t* data_p,int data_size,int dead_time = 100)

## ポーリングモードでデータを送信する関数． [パラメータ] 送信データ配列の先頭アドレス 送信データ配列の⼤きさ デッドタイム．デフォルトでは100[ms]

## [戻り値]

なし

## [サンプルコード]

#include "stm32f4xx.h"; #include "sken_library/include.h"; Uart serial;; uint8_t data[2] = {1,2};; int main(void); sken_system.init();; serial.init(A9,A10,SERIAL1,9600);; while(1); serial.write(data,2);

# bool Uart::checkTimeOut(void)

## ポーリングモードでデータを受信した際の通信切断を確認できる

## [パラメータ]

なし

## [戻り値] タイムアウトフラグ [サンプルコード]

#include "stm32f4xx.h"; #include "sken_library/include.h"; Uart serial;; uint8_t data;; int main(void); sken_system.init();; serial.init(A9,A10,SERIAL1,9600);; while(1); data = serial.read(1000); if(serial.checkTimeOut){

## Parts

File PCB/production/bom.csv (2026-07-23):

Designator | Footprint | Quantity | Value | LCSC Part #
C1, C2 | 0603 | 2 | 20p
C10 | 0603 | 1 | 22u
C3 | 0603 | 1 | 0.1u
C4, C5, C6, C7, C8 | 0603 | 5 | 1u
C9 | 0603 | 1 | 10u
D1 | LED_ROHM_SMLVN6 | 1 | SMLVN6RGB
D2, D3 | 0603 | 2 | LED_Small
H1, H2, H3, H4 | MountingHole_3.2mm_M3_Pad_Via | 4 | MountingHole
J1 | PinSocket_1x05_P2.54mm_Vertical | 1 | Conn_01x05
J2, J3, J4 | JST_XA_S02B-XASK-1_1x02_P2.50mm_Horizontal | 3 | Conn_01x02
R1, R2, R3, R4, R5 | 0603 | 5 | 500
SW1 | SW_Push_1P1T_NO_CK_KMR2 | 1 | SW_Push
U1 | LQFP-64_10x10mm_P0.5mm | 1 | STM32F446RETx
U2 | SOT-223 | 1 | AZ1117CH-3.3TRG1
U3, U4 | SOIC-8_3.9x4.9mm_P1.27mm | 2 | MCP2551-I-SN
Y1 | Crystal_SMD_5032-4Pin_5.0x3.2mm | 1 | 8M

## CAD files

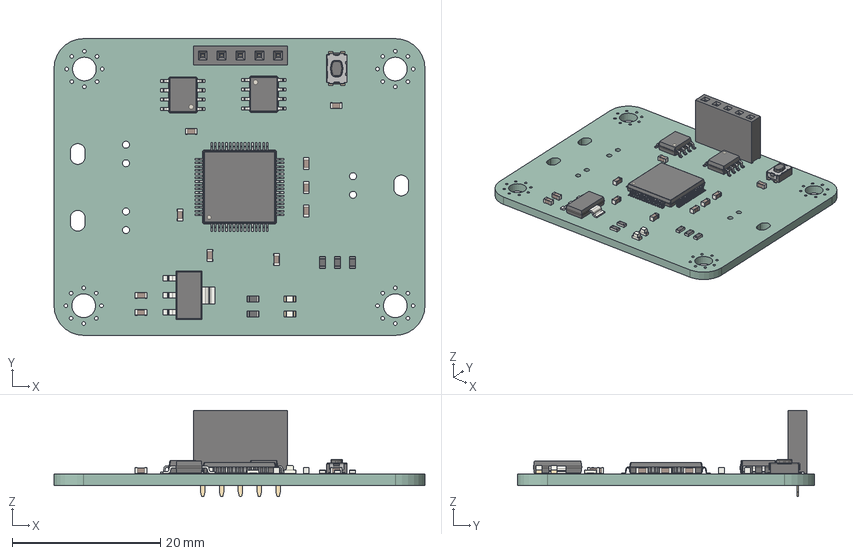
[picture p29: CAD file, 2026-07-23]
PCB/robomas_turn.step
50.0 x 40.0 x 11.6 mm
C_0603_1608Metric x 10
R_0603_1608Metric x 5
LQFP-64_10x10mm_P0.5mm
SW_Push_1P1T_NO_CK_KMR2
LED_0603_1608Metric x 2
SOT-223
PinSocket_1x05_P2.54mm_Vertical
SOIC-8_3.9x4.9mm_P1.27mm x 2
robomas_turn_PCB

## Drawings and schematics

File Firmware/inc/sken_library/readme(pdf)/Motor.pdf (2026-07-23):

# Motor

## モーターを制御するためのクラス

# class Motor

# void Motor::init(Pin pin_a,Pin pin_p,Pin

pin_b,TimerNumber timer,TimerChannel ch);

## ピン、タイマー、チャンネルの設定

## [パラメータ] Aピン

## PWMピン

## Bピン タイマー番号 タイマーチャンネル

## [戻り値]

なし

## [サンプルコード] C2をAピン、C3をBピン、C8をPWMピンに設定

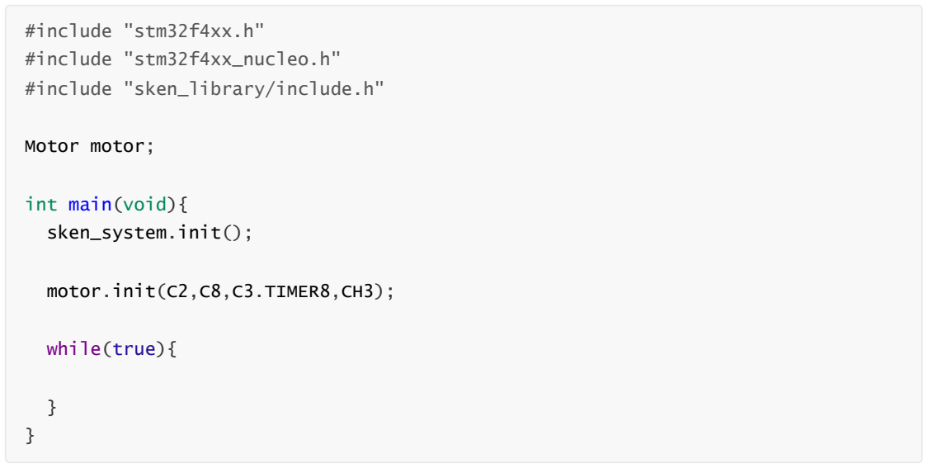
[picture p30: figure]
#include "stm32f4xx.h"; #include "stm32f4xx_nucleo.h"; #include "sken_library/include.h"; Motor motor;; int main(void){; sken_system.init();; motor.init(C2,C8,C3.TIMER8,CH3);; while(true){

void Motor::write(int val);

## モーターを回す関数

## [パラメータ]

## PWM値（-100~100）

## 負の数は逆回転を表す

## [戻り値]

なし

## [サンプルコード] モータをPWM値30で正回転

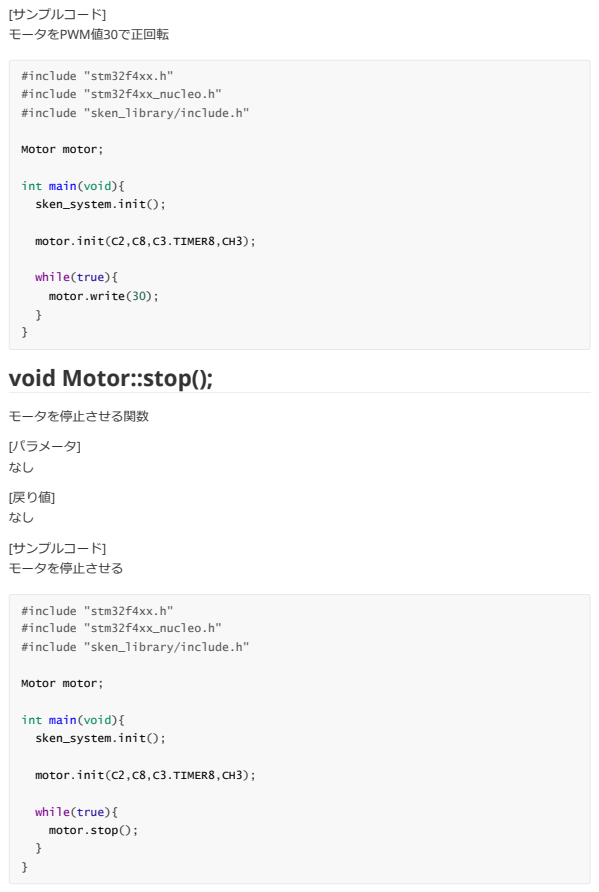
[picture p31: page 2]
void Motor::stop();; モータを停止させる関数; [パラメータ] なし; [戻り値] なし; [サンプルコード] モータを停止させる; #include "stm32f4xx.h"; #include "stm32f4xx_nucleo.h"; #include "sken_library/include.h"; Motor motor;; motor.init(C2,C8,C3.TIMER8,CH3);; while(true){; motor.write(30);; motor.stop();

int main(void){
sken_system.init();

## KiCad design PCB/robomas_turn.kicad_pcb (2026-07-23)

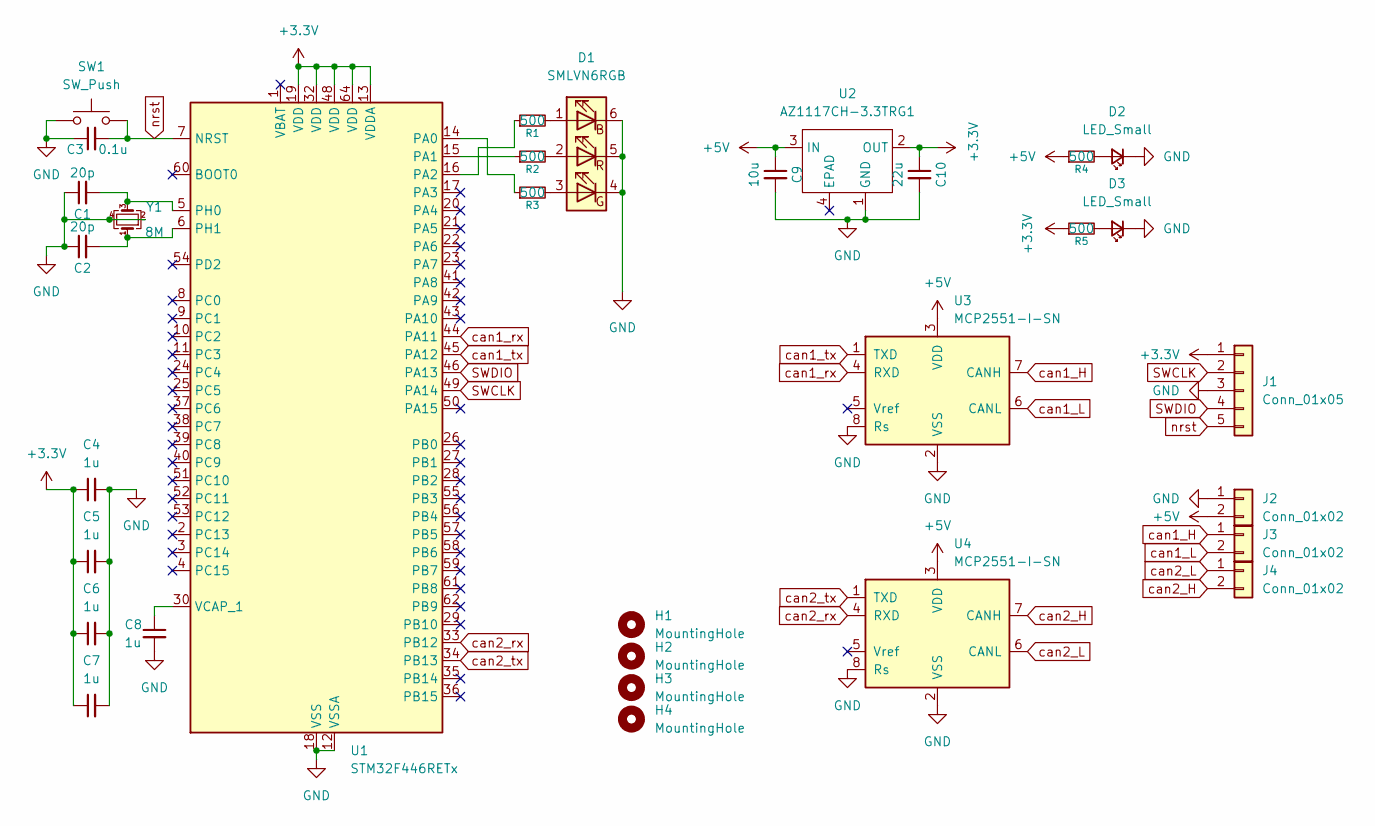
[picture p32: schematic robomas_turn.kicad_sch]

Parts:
C1, C2: 20p; C_0603_1608Metric
C3: 0.1u; C_0603_1608Metric
C4, C5, C6, C7, C8: 1u; C_0603_1608Metric
C9: 10u; C_0603_1608Metric
C10: 22u; C_0603_1608Metric
D1: SMLVN6RGB; LED_ROHM_SMLVN6
D2, D3: LED_Small; LED_0603_1608Metric
H1, H2, H3, H4: MountingHole; MountingHole_3.2mm_M3_Pad_Via
J1: Conn_01x05; PinSocket_1x05_P2.54mm_Vertical
J2, J3, J4: Conn_01x02; JST_XA_S02B-XASK-1_1x02_P2.50mm_Horizontal
R1, R2, R3, R4, R5: 500; R_0603_1608Metric
SW1: SW_Push; SW_Push_1P1T_NO_CK_KMR2
U1: STM32F446RETx; LQFP-64_10x10mm_P0.5mm
U2: AZ1117CH-3.3TRG1; SOT-223
U3, U4: MCP2551-I-SN; SOIC-8_3.9x4.9mm_P1.27mm
Y1: 8M; Crystal_SMD_5032-4Pin_5.0x3.2mm

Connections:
+3.3V: C4.1, C5.1, C6.1, C7.1, C10.1, J1.1, R5.1, U1.13 (VDDA), U1.19 (VDD), U1.32 (VDD), U1.48 (VDD), U1.64 (VDD), U2.2 (OUT)
+5V: C9.1, J2.2, R4.1, U2.3 (IN), U3.3 (VDD), U4.3 (VDD)
GND: C1.1, C2.1, C3.1, C4.2, C5.2, C6.2, C7.2, C8.2, C9.2, C10.2, D1.4 (GK), D1.5 (RK), D1.6 (BK), D2.1 (K), D3.1 (K), J1.3, J2.1, SW1.1, U1.12 (VSSA), U1.18 (VSS), U1.31 (VSS), U1.47 (VSS), U1.63 (VSS), U2.1 (GND), U3.2 (VSS), U3.8 (Rs), U4.2 (VSS), U4.8 (Rs), Y1.2, Y1.4
unnamed: D1.1 (BA), R1.2
unnamed: D1.3 (GA), R3.2
unnamed: D1.2 (RA), R2.2
unnamed: D2.2 (A), R4.2
unnamed: D3.2 (A), R5.2
unnamed: R3.1, U1.14 (PA0)
unnamed: R2.1, U1.15 (PA1)
unnamed: R1.1, U1.16 (PA2)
unnamed: C1.2, U1.5 (PH0), Y1.3
unnamed: C2.2, U1.6 (PH1), Y1.1
unnamed: C8.1, U1.30 (VCAP_1)
SWCLK: J1.2, U1.49 (PA14)
SWDIO: J1.4, U1.46 (PA13)
can1_H: J3.1, U3.7 (CANH)
can1_L: J3.2, U3.6 (CANL)
can1_rx: U1.44 (PA11), U3.4 (RXD)
can1_tx: U1.45 (PA12), U3.1 (TXD)
can2_H: J4.2, U4.7 (CANH)
can2_L: J4.1, U4.6 (CANL)
can2_rx: U1.33 (PB12), U4.4 (RXD)
can2_tx: U1.34 (PB13), U4.1 (TXD)
nrst: C3.2, J1.5, SW1.2, U1.7 (NRST)

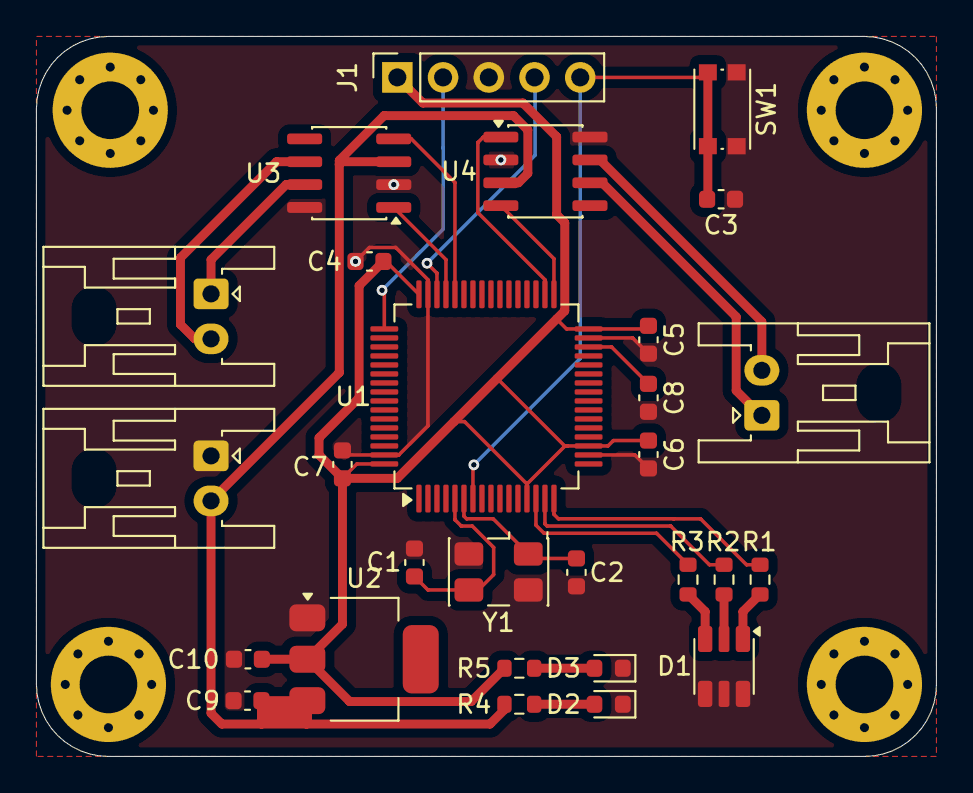
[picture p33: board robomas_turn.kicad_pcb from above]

Board: 2 copper layers, 50.0 x 40.0 mm, 32 parts (0 on the bottom side), 25 nets.

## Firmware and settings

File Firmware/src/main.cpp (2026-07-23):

/**
  ******************************************************************************
  * @file    main.c
  * @author  Ac6
  * @version V1.0
  * @date    01-December-2013
  * @brief   Default main function.
  ******************************************************************************
*/


#include "stm32f4xx.h"
#include "stm32f4xx_nucleo.h"
#include "sken_library/include.h"
#include <cmath>

#define COMMAND_TIMEOUT_MS 500
#define m2006_P 36
#define m3508_P 19

enum Motor_Type{
    motor_none = 0,
	m2006 = 1,
	m3508 = 2
};

enum Control_Type{
	speed = 1,
	position = 2
};
			
Gpio LED[3];
long unsigned int time;

CanData can1_data,can2_data;
uint8_t debug_data[8],RoboMas_data[8];

Pid speed_pid[2][4],position_pid[2][4];

uint8_t motor_type[4],control_type[4],motor_EN[4],angle_reset[4];
uint32_t last_command_time[4];
int motor_ratio[4];
double motor_out[4],motor_rps[4],motor_rad[4],target_rps[4],target_rad[4];

void RoboMas_turn()
{
    static uint16_t previous_rot[4];
    static int32_t total_rot[4];
    static bool initialized[4];

    static double motor_rad_offset[4];
    static uint8_t previous_angle_reset[4];

    if (can2_data.rx_stdid < 0x201 ||
        can2_data.rx_stdid > 0x204) {
        return;
    }

    int i = can2_data.rx_stdid - 0x201;

    if (motor_ratio[i] <= 0) {
        return;
    }

    uint16_t current_rot =
        ((uint16_t)can2_data.rx_data[0] << 8) |
        can2_data.rx_data[1];

    int16_t motor_rpm =
        (int16_t)(
            ((uint16_t)can2_data.rx_data[2] << 8) |
            can2_data.rx_data[3]
        );

    motor_rps[i] =
        (double)motor_rpm /
        60.0 /
        (double)motor_ratio[i];

    if (!initialized[i]) {
        previous_rot[i] = current_rot;
        total_rot[i] = 0;
        initialized[i] = true;
    } else {
        int32_t difference =
            (int32_t)current_rot -
            (int32_t)previous_rot[i];

        if (difference > 4096) {
            difference -= 8192;
        } else if (difference < -4096) {
            difference += 8192;
        }

        total_rot[i] += difference;
        previous_rot[i] = current_rot;
    }

    double raw_motor_rad =
        (double)total_rot[i] *
        2.0 * M_PI /
        8192.0 /
        (double)motor_ratio[i];

    if (angle_reset[i] == 1 &&
    	previous_angle_reset[i] == 0) {

        motor_rad_offset[i] = raw_motor_rad;

        position_pid[0][i].reset();
        position_pid[1][i].reset();
    }


    previous_angle_reset[i] = angle_reset[i];

    motor_rad[i] = raw_motor_rad - motor_rad_offset[i];
}

void rcv_command()
{
    static uint8_t motor_EN_[4];

    for (int i = 0; i < 4; i++) {
        if (can1_data.rx_stdid != (0x221 + i)) {
            continue;
        }

        uint8_t received_motor_type =
            can1_data.rx_data[0];

        uint8_t received_control_type =
            can1_data.rx_data[1];

        uint8_t received_enable =
            can1_data.rx_data[4];

        uint8_t received_angle_reset =
            can1_data.rx_data[5];

        if (received_motor_type != m2006 &&
            received_motor_type != m3508) {
            return;
        }

        if (received_control_type != speed &&
            received_control_type != position) {
            return;
        }

        if (received_enable > 1) {
            return;
        }

        int16_t target_raw =
            (int16_t)(
                ((uint16_t)can1_data.rx_data[2] << 8) |
                can1_data.rx_data[3]
            );

        motor_type[i] = received_motor_type;
        control_type[i] = received_control_type;
        motor_EN[i] = received_enable;

        angle_reset[i] =
            received_angle_reset != 0 ? 1 : 0;

        if (motor_EN[i] == 1 &&
            motor_EN_[i] == 0) {

            speed_pid[0][i].reset();
            position_pid[0][i].reset();
            speed_pid[1][i].reset();
            position_pid[1][i].reset();
        }

        motor_EN_[i] = motor_EN[i];

        if (motor_type[i] == m2006) {
            motor_ratio[i] = m2006_P;
        } else {
            motor_ratio[i] = m3508_P;
        }

        double received_target =
            (double)target_raw / 1000.0;

        if (control_type[i] == speed) {
            target_rps[i] = received_target;
        } else {
            target_rad[i] = received_target;
        }

        last_command_time[i] =
            sken_system.millis();
    }
}

void make_debug_data()
{
    for (int i = 0; i < 4; i++) {
        double error = 0.0;

        if (control_type[i] == speed) {
            error = target_rps[i] - motor_rps[i];
        }
        else if (control_type[i] == position) {
            error = target_rad[i] - motor_rad[i];
        }

        double scaled_error = error * 1000.0;

        if (scaled_error > 32767.0) {
            scaled_error = 32767.0;
        }
        else if (scaled_error < -32768.0) {
            scaled_error = -32768.0;
        }

        int16_t error_raw =
            (int16_t)scaled_error;

        debug_data[i * 2] =
            (uint8_t)((error_raw >> 8) & 0xFF);

        debug_data[i * 2 + 1] =
            (uint8_t)(error_raw & 0xFF);
    }
}

void transmit_debug()
{
    static uint32_t previous_time = 0;

    uint32_t now = sken_system.millis();

    if (now - previous_time < 10) {
        return;
    }

    previous_time = now;

    make_debug_data();

    sken_system.canTransmit(
        CAN_1,
        0x230,
        debug_data,
        8,
        0,
        stdid
    );
}

void write_LED(int num)
{
	switch (num)
	{
	case 0:
		for (int i=0;i<3;i++) LED[i].write(LOW);
		break;

	case 1:
		if (motor_EN[0] == 0){			//bright red
			for (int i=0;i<2;i++) LED[i*2].write(LOW);
			LED[1].write(HIGH);
		}else if (motor_EN[0] == 1){	//brgith red,blue,green
			if (motor_type[0] == m2006 && control_type[0] == speed){			//Green
				LED[0].write(HIGH);
				LED[1].write(LOW);
				LED[2].write(LOW);
			}else if (motor_type[0] == m2006 && control_type[0] == position){	//Yellow
				LED[0].write(HIGH);
				LED[1].write(HIGH);
				LED[1].write(HIGH);
			}else if (motor_type[0] == m3508 && control_type[0] == speed){		//Blue
				LED[0].write(LOW);
				LED[1].write(LOW);
				LED[2].write(HIGH);
			}else if (motor_type[0] == m3508 && control_type[0] == position){	//SkyBlue
				LED[0].write(HIGH);
				LED[1].write(LOW);
				LED[2].write(HIGH);
			}
		}
		break;

	case 2:
		if (motor_EN[1] == 0){			//bright red
			for (int i=0;i<2;i++) LED[i*2].write(LOW);
			LED[1].write(HIGH);
		}else if (motor_EN[1] == 1){	//brgith blue,green
			if (motor_type[1] == m2006 && control_type[1] == speed){			//Green
				LED[0].write(HIGH);
				LED[1].write(LOW);
				LED[2].write(LOW);
			}else if (motor_type[1] == m2006 && control_type[1] == position){	//Yellow
				LED[0].write(HIGH);
				LED[1].write(HIGH);
				LED[1].write(HIGH);
			}else if (motor_type[1] == m3508 && control_type[1] == speed){		//Blue
				LED[0].write(LOW);
				LED[1].write(LOW);
				LED[2].write(HIGH);
			}else if (motor_type[1] == m3508 && control_type[1] == position){	//SkyBlue
				LED[0].write(HIGH);
				LED[1].write(LOW);
				LED[2].write(HIGH);
			}
		}
		break;

	case 3:
		if (motor_EN[2] == 0){			//bright red
			for (int i=0;i<2;i++) LED[i*2].write(LOW);
			LED[1].write(HIGH);
		}else if (motor_EN[2] == 1){	//brgith blue,green
			if (motor_type[2] == m2006 && control_type[2] == speed){			//Green
				LED[0].write(HIGH);
				LED[1].write(LOW);
				LED[2].write(LOW);
			}else if (motor_type[2] == m2006 && control_type[2] == position){	//Yellow
				LED[0].write(HIGH);
				LED[1].write(HIGH);
				LED[1].write(HIGH);
			}else if (motor_type[2] == m3508 && control_type[2] == speed){		//Blue
				LED[0].write(LOW);
				LED[1].write(LOW);
				LED[2].write(HIGH);
			}else if (motor_type[2] == m3508 && control_type[2] == position){	//SkyBlue
				LED[0].write(HIGH);
				LED[1].write(LOW);
				LED[2].write(HIGH);
			}
		}
		break;
	case 4:
		if (motor_EN[3] == 0){			//bright red
			for (int i=0;i<2;i++) LED[i*2].write(LOW);
			LED[1].write(HIGH);
		}else if (motor_EN[3] == 1){	//brgith blue,green
			if (motor_type[3] == m2006 && control_type[3] == speed){			//Green
				LED[0].write(HIGH);
				LED[1].write(LOW);
				LED[2].write(LOW);
			}else if (motor_type[3] == m2006 && control_type[3] == position){	//Yellow
				LED[0].write(HIGH);
				LED[1].write(HIGH);
				LED[1].write(HIGH);
			}else if (motor_type[3] == m3508 && control_type[3] == speed){		//Blue
				LED[0].write(LOW);
				LED[1].write(LOW);
				LED[2].write(HIGH);
			}else if (motor_type[3] == m3508 && control_type[3] == position){	//SkyBlue
				LED[0].write(HIGH);
				LED[1].write(LOW);
				LED[2].write(HIGH);
			}
		}
		break;
	}
}

void check_command_timeout()
{
    uint32_t now = sken_system.millis();

    for (int i = 0; i < 4; i++) {
        if (motor_EN[i] == 1 &&
            (uint32_t)(now - last_command_time[i]) >
            COMMAND_TIMEOUT_MS) {

            motor_EN[i] = 0;

            motor_out[i] = 0.0;
            target_rps[i] = 0.0;

            speed_pid[0][i].reset();
            position_pid[0][i].reset();
            speed_pid[1][i].reset();
            position_pid[1][i].reset();
        }
    }
}

double limitValue(
    double value,
    double min_value,
    double max_value
)
{
    if (value > max_value) {
        return max_value;
    }

    if (value < min_value) {
        return min_value;
    }

    return value;
}

void interrupt()
{
    for (int i = 0; i < 4; i++) {
        double calculated_output = 0.0;

        if (motor_EN[i] == 1 &&
            motor_type[i] != motor_none) {

            int type_index = motor_type[i] - 1;

            if (control_type[i] == speed) {
                calculated_output =
                    speed_pid[type_index][i].control(
                        target_rps[i],
                        motor_rps[i],
                        1
                    );
            }
            else if (control_type[i] == position) {
                double target_speed =
                    position_pid[type_index][i].control(
                        target_rad[i],
                        motor_rad[i],
                        1
                    );

                double max_rps = 0.0;

                if (motor_type[i] == m2006) {
                    max_rps = 2.0;
                }
                else if (motor_type[i] == m3508) {
                    max_rps = 6.7;
                }

                target_speed =
                    limitValue(
                        target_speed,
                        -max_rps,
                        max_rps
                    );

                calculated_output =
                    speed_pid[type_index][i].control(
                        target_speed,
                        motor_rps[i],
                        1
                    );
            }
        }

        double output_limit = 0.0;

        if (motor_type[i] == m2006) {
            output_limit = 10000.0;
        }
        else if (motor_type[i] == m3508) {
            output_limit = 16000.0;
        }

        calculated_output =
            limitValue(
                calculated_output,
                -output_limit,
                output_limit
            );

        motor_out[i] = calculated_output;

        int16_t command =
            (int16_t)motor_out[i];

        RoboMas_data[i * 2] =
            (uint8_t)((command >> 8) & 0xFF);

        RoboMas_data[i * 2 + 1] =
            (uint8_t)(command & 0xFF);
    }

    sken_system.canTransmit(
        CAN_2,
        0x200,
        RoboMas_data,
        8,
        0,
        stdid
    );
}

int main(void)
{
	sken_system.init();

	LED[0].init(A0,OUTPUT); //Green
	LED[1].init(A1,OUTPUT); //Red
	LED[2].init(A2,OUTPUT); //Blue

	sken_system.startCanCommunicate(A12,A11,CAN_1);
	sken_system.startCanCommunicate(B13,B12,CAN_2);
	sken_system.addCanRceiveInterruptFunc(CAN_1,&can1_data);
	sken_system.addCanRceiveInterruptFunc(CAN_2,&can2_data);

	for (int i = 0; i < 4; i++) {
		speed_pid[0][i].setGain(3000,1000,1,1); 		//timeconstant = 1 rps_Gain for m2006
		position_pid[0][i].setGain(3,0.1,0,1); 	//timeconstant = 1 rps_Gain for m2006
	    speed_pid[1][i].setGain(3000, 1000, 10, 1); 	//timeconstant = 1 rps_Gain for m3508
	    position_pid[1][i].setGain(2, 0.1, 0, 1); 		//timeconstant = 1 radian_Gain for m3508
	}

	sken_system.addTimerInterruptFunc(interrupt,0,1);
	while(true){
		time = sken_system.millis()/500;
		if(time%9 == 0){
			write_LED(1);
		}else if(time%9 == 2){
			write_LED(2);
		}else if(time%9 == 4){
			write_LED(3);
		}else if(time%9 == 6){
			write_LED(4);
		}else{
			write_LED(0);
		}

		rcv_command();
		RoboMas_turn();
	    check_command_timeout();
		transmit_debug();
	}
}

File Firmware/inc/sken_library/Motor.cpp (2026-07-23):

/*
 * Motor.cpp
 *
 *  Created on: 2021/06/23
 *      Author: hotaka
 */

/*
 * モーターを制御するクラス
*/

#include "Motor.h"

Motor::Motor(){}

void Motor::init(Pin pin1,Pin pinP,Pin pin2,TimerNumber timer,TimerChannel ch){
	mtr_name_ = ShibaDriver;
	motor[0].init(pin1,OUTPUT);
	motor[1].init(pinP,PWM_OUTPUT,timer,ch,980);
	motor[2].init(pin2,OUTPUT);
}

void Motor::init(MtrPin mtr_pin,Pin pin,TimerNumber timer,TimerChannel ch){
	mtr_name_ = KuroDriver;
	motor[mtr_pin].init(pin,PWM_OUTPUT,timer,ch,50000);
}

void Motor::write(int val){
	if(mtr_name_ == ShibaDriver){
		if(val == 0){
			motor[0].write(LOW);
			motor[1].write(val);
			motor[2].write(LOW);
		}else if(val > 0){
			motor[0].write(HIGH);
			motor[1].write(val);
			motor[2].write(LOW);
		}else if(val < 0){
			motor[0].write(LOW);
			motor[1].write(-1*val);
			motor[2].write(HIGH);
		}
	}else if(mtr_name_ == KuroDriver){
		if(val == 0){
			motor[0].write(0);
			motor[1].write(0);
		}else if(val > 0){
			motor[0].write(val);
			motor[1].write(0);
		}else if(val < 0){
			motor[0].write(0);
			motor[1].write(-1*val);
		}else if(val > 99){
			motor[0].write(99);
			motor[1].write(0);
		}else if(val < -99){
			motor[0].write(0);
			motor[1].write(-1*val);
		}
	}
}

void Motor::stop(){
	if(mtr_name_ ==  ShibaDriver){
		motor[0].write(HIGH);
		motor[1].write(0);
		motor[2].write(HIGH);
	}else if(mtr_name_ == KuroDriver){
		motor[0].write(0);
		motor[1].write(0);
	}
}

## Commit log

2026-07-23 Add STM32F4 HAL Driver version to README
2026-07-23 Add initial README for PCB design project
2026-07-23 Update images in README for PCB and 3D view
